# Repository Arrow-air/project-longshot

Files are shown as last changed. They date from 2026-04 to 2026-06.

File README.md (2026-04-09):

# Project Longshot

Custom 21700 Li-ion battery pack for the [Quiver](https://github.com/Arrow-air/project-quiver) drone platform.

## Overview

Longshot replaces the commercial Tattu battery with a custom-built 21700 cell pack, delivering significantly more energy in the same form factor. The pack is designed for open-source tooling and compatibility with the existing Quiver power system.

## Specifications

| Parameter | Value |
|---|---|
| Configuration | 14S 9P (126 cells) |
| Cell format | 21700 Li-ion |
| Energy | ~2,200–2,300 Wh |
| Voltage | 14S (~58.8V charged, ~51.8V nominal) |
| Communication | CAN H/L on main connector |
| Environmental | IP54, 4× temperature sensors |
| Structure | Printed cell holders + casing, aluminum reinforcement |
| Bus bars | Laser-cut 0.2mm copper foil |

## BMS

- **v0 (prototype):** PCB dummy — exposes cell connections, main PCB handles power path
- **v1+:** STM32-based smart BMS (VESC BMS reference design)

## Status

Project approved via [Snapshot vote](https://snapshot.box/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) (April 2026, amends AIP-007).

## Links

- [Proposal discussion](https://dao.arrowair.com/t/project-longshot-proposal-discussion/154)
- [Arrow DAO](https://arrowair.com)
- [Project Quiver](https://github.com/Arrow-air/project-quiver)

## License

See [CONTRIBUTING.md](CONTRIBUTING.md) for contribution guidelines.

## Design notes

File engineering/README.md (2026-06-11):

# Engineering

This folder contains the active design work for Project Longshot.

- `cad/` — mechanical CAD, generated exports, and reference geometry.
- `electronics/` — PCB projects and electronics design files.
- `builds/` — build-specific locked artifacts, order packages, and design records.

Keep durable decisions and explanatory documents in `docs/`. Use GitHub issues and discussions for live work-in-progress updates, then summarize settled outcomes back into the relevant README or ADR.

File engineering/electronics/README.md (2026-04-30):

# Electronics

Longshot electronics design files live here.

## PCB projects

Each PCB should have its own self-contained folder under `pcbs/`. KiCad projects should keep project files under `kicad/` and local libraries under `kicad/libs/` so a contributor can clone/download the PCB folder and open it without missing project-specific components.

Current PCB folders:

- `pcbs/BMSJ/` — Longshot BMSJ battery management system board.
- `pcbs/BMSZ/` — Longshot BMSZ battery management system board.

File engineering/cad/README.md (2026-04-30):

# CAD

Longshot CAD work lives here.

## Folders

- `build123d/` — Python/build123d parametric CAD source.
- `reference/` — imported vendor, measurement, or reference geometry.
- `build123d/exports/` — generated STEP/STL outputs for review, manufacturing, or downstream CAD use.

Generated exports should be reproducible from the source where practical. If an export is hand-edited or comes from another CAD package, document that in the nearest README.

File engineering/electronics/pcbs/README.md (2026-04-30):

# PCB Projects

Each folder in this directory is one self-contained PCB project.

## Required PCB folder contents

```text
PCBNAME/
├── README.md
├── docs/
├── firmware/
├── images/
├── kicad/
│   └── libs/
│       ├── 3dmodels/
│       ├── PCBNAME.pretty/
│       └── PCBNAME.kicad_sym
└── manufacturing/
```

## KiCad conventions

- Put KiCad project files directly under `kicad/`.
- Put project-local symbols, footprints, and 3D models under `kicad/libs/`.
- Use `kicad/libs/PCBNAME.pretty/` for the board's local footprint library.
- Use `kicad/libs/PCBNAME.kicad_sym` for the board's local symbol library.
- Avoid relying on contributor-specific global KiCad libraries for project components. If a component is not from KiCad's standard libraries, include it locally in the PCB folder.

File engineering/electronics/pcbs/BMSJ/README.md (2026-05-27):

# BMSJ

Open-source Battery Management System designed for high-voltage lithium battery packs with VESC integration.

## Longshot Repository Layout

This project was imported from `Julius-eng/Vector-BMS` and adapted into the Project Longshot engineering tree.

- `kicad/` — KiCad project, schematic sheets, PCB, and project-local library tables.
- `kicad/libs/BMSJ.pretty/` — project-local footprints imported from the source repository.
- `firmware/vesc_bms_hw/` — VESC BMS hardware configuration renamed to `hw_bmsj`.
- `docs/`, `images/`, and `manufacturing/` — placeholders for supporting design notes, renders, and fab outputs.

## Overview

BMSJ is a modular BMS supporting up to **24 series cells** (24S) with:
- Active cell monitoring and balancing
- High-current sensing (up to 120A)
- CAN bus communication (VESC-compatible)
- USB interface for configuration
- Isolated design for safety

**Firmware:** This project uses [VESC BMS firmware](https://github.com/vedderb/vesc_bms_fw) for full VESC Tool integration.

## Hardware Architecture

### Schematic Structure

```
BMSJ.kicad_sch (Main)
├── Power management
├── Cell monitoring (LTC6811 × 2)
├── Current sensing (INA226)
├── High-side switching
└── Connectors

MCU.kicad_sch
├── STM32L476 microcontroller
├── CAN interface (isolated via ISO1050)
├── isoSPI interface (LTC6820)
└── USB interface (CP2104)

cell.kicad_sch / cell2.kicad_sch
└── Per-cell balancing circuits (×12 each)
```

### Key Components

| Component | Part Number | Function |
|---|---|---|
| MCU | STM32L476RGT6 | ARM Cortex-M4, 80MHz, low power |
| Cell Monitor | LTC6811-1 (×2) | 12-cell stack monitor, ±1.2mV accuracy |
| isoSPI | LTC6820 | Isolated SPI for LTC6811 daisy chain |
| Current Sensor | INA226 | 16-bit I2C power monitor |
| Shunt Resistor | WSLP5931L1000FEA | 0.1mΩ, 15W, ±1% |
| CAN Transceiver | ISO1050DUBR | Isolated CAN 2.0B |
| USB-UART | CP2104 | USB to UART bridge |
| DC-DC | LM5165 | Wide-input buck converter |
| Balance FET | DMG2305UX-7 | P-ch MOSFET, SOT-23 |
| Balance Resistor | CRCW25123R90JNEA | 3.9Ω, 1W, 2512 |
| High-side Switch | IRFL4105PBF | N-ch logic-level MOSFET |

### Cell Configuration

- **Maximum cells:** 24S (two LTC6811 in daisy chain)
- **Cell voltage range:** 0V to 5V per cell (compatible with most Li-ion/LiFePO4)
- **Balance current:** ~1A per cell @ 4.2V (passive balancing via 3.9Ω resistor)
- **Temperature monitoring:** 3× NTC thermistors

### Current Sensing

- **Shunt:** 0.1mΩ (WSLP5931, 15×7.6mm)
- **Max continuous:** 120A
- **Sensor:** INA226 (16-bit I2C power monitor)
- **Resolution:** ~1mA per LSB
- **Power dissipation:** 1.44W at 120A

## VESC BMS Firmware

BMSJ uses the [VESC BMS firmware](https://github.com/vedderb/vesc_bms_fw) which provides:

- ✅ Cell monitoring and balancing
- ✅ Charge control with CC/CV support
- ✅ Low-power sleep mode
- ✅ CAN-bus integration with VESC motor controllers
- ✅ USB configuration via VESC Tool
- ✅ Ah and Wh counting
- ✅ Distributed balancing across multiple BMSes
- ✅ Bootloader and firmware update support

### Building Firmware

#### Prerequisites

1. **ARM GCC Toolchain**
   ```bash
   # Ubuntu/Debian
   sudo apt install gcc-arm-none-eabi

   # macOS
   brew install arm-none-eabi-gcc

   # Windows: Download from ARM website
   ```

2. **ChibiOS** (included as submodule in VESC BMS)

3. **Make**

#### Clone and Build

```bash
# Clone VESC BMS firmware
git clone --recursive https://github.com/vedderb/vesc_bms_fw.git
cd vesc_bms_fw

# Copy BMSJ hardware config
cp /path/to/project-longshot/engineering/electronics/pcbs/BMSJ/firmware/vesc_bms_hw/hw_bmsj.h hwconf/
cp /path/to/project-longshot/engineering/electronics/pcbs/BMSJ/firmware/vesc_bms_hw/hw_bmsj.c hwconf/

# Build for BMSJ
make HWCONF=hw_bmsj

# Output: build/vesc_bms_fw.bin
```

#### Flashing

Using ST-Link:
```bash
# Flash via OpenOCD
openocd -f interface/stlink.cfg -f target/stm32l4x.cfg \
    -c "program build/vesc_bms_fw.bin 0x08000000 verify reset exit"

# Or via st-flash
st-flash write build/vesc_bms_fw.bin 0x08000000
```

Using VESC Tool (for updates):
1. Connect BMSJ via USB
2. Open VESC Tool
3. Go to **Firmware** → **Bootloader**
4. Select `vesc_bms_fw.bin` and upload

### Hardware Configuration

The BMSJ hardware config is in `firmware/vesc_bms_hw/`:

```
firmware/vesc_bms_hw/
├── hw_bmsj.h     # Pin definitions, parameters
└── hw_bmsj.c     # Initialization, INA226 driver
```

Key parameters in `hw_bmsj.h`:

```c
#define HW_CELLS_SERIES         24          // Cell count
#define HW_SHUNT_RES            (0.1e-3)    // Shunt resistance
#define HW_INA226_I2C_ADDR      0x40        // INA226 address
```

### VESC Tool Configuration

1. Connect BMSJ via USB
2. Open VESC Tool and connect
3. Go to **VESC BMS** tab
4. Configure:
   - Cell count: 24
   - Balance start voltage
   - Balance delta voltage
   - Current limits
   - Temperature limits
5. **Write Configuration**

## MCU Pin Mapping

| Function | STM32 Pin | Notes |
|---|---|---|
| SPI1_NSS (LTC6820) | PA4 | Directly driven CS |
| SPI1_SCK | PA5 | isoSPI clock |
| SPI1_MISO | PA6 | isoSPI data in |
| SPI1_MOSI | PA7 | isoSPI data out |
| I2C1_SDA (INA226) | PB7 | Current sensor |
| I2C1_SCL | PB6 | Current sensor |
| CAN1_RX | PB8 | Via ISO1050 |
| CAN1_TX | PB9 | Via ISO1050 |
| USART1_TX | PA9 | Via CP2104 to USB |
| USART1_RX | PA10 | Via CP2104 to USB |
| CHG_EN | PC6 | Charge enable |
| DSG_EN | PC7 | Discharge enable |
| PCHG_EN | PC8 | Precharge enable |
| LED_RED | PA0 | Status LED |
| LED_GREEN | PA1 | Power LED |
| BUZZER | PA8 | Audible alarm |

## Connectors

| Connector | Function |
|---|---|
| J1 | Main battery input |
| J2 | Charger input |
| J3 | OLED display (I2C) |
| J12 | CAN bus |
| J14 | Serial/debug |
| J17 | Power button |
| J24 | USB (CP2104) |

## Hardware Design

### Prerequisites

- KiCad 9.0+ for schematic/PCB editing

### Opening the Project

1. Clone the repository
2. Open `kicad/BMSJ.kicad_pro` in KiCad
3. Review schematic and PCB layout
4. Generate BOM and fabrication files

## License

Hardware: Open Source (license TBD)
Firmware: GNU GPL v3 (VESC BMS)

## Contributing

Contributions welcome! Please open an issue or pull request.

## Acknowledgments

- [Benjamin Vedder](https://github.com/vedderb) for VESC BMS firmware
- VESC Project for the open-source motor controller ecosystem
- Analog Devices for LTC6811 reference designs
- Arrow DAO community

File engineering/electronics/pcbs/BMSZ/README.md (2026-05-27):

# BMSZ

Open-source Battery Management System designed for high-voltage lithium battery packs with VESC integration.

## Longshot Repository Layout

This project was imported from `Julius-eng/Vector-BMS` and adapted into the Project Longshot engineering tree.

- `kicad/` — KiCad project, single-sheet schematic, PCB, and project-local library tables.
- `kicad/libs/BMSZ.pretty/` — project-local footprints imported from the source repository.
- `firmware/vesc_bms_hw/` — VESC BMS hardware configuration renamed to `hw_bmsz`.
- `docs/`, `images/`, and `manufacturing/` — placeholders for supporting design notes, renders, and fab outputs.

## Overview

BMSZ is a modular BMS supporting up to **24 series cells** (24S) with:
- Active cell monitoring and balancing
- High-current sensing (up to 120A)
- CAN bus communication (VESC-compatible)
- USB interface for configuration
- Isolated design for safety

**Firmware:** This project uses [VESC BMS firmware](https://github.com/vedderb/vesc_bms_fw) for full VESC Tool integration.

## Hardware Architecture

### Schematic Structure

`BMSZ.kicad_sch` is currently reduced to a single basic-layout schematic. The previous copied hierarchy (`MCU.kicad_sch`, `cell.kicad_sch`, and `cell2.kicad_sch`) has been removed from this simplified layout.

### Key Components

| Component | Part Number | Function |
|---|---|---|
| MCU | STM32L476RGT6 | ARM Cortex-M4, 80MHz, low power |
| Cell Monitor | LTC6811-1 (×2) | 12-cell stack monitor, ±1.2mV accuracy |
| isoSPI | LTC6820 | Isolated SPI for LTC6811 daisy chain |
| Current Sensor | INA226 | 16-bit I2C power monitor |
| Shunt Resistor | WSLP5931L1000FEA | 0.1mΩ, 15W, ±1% |
| CAN Transceiver | ISO1050DUBR | Isolated CAN 2.0B |
| USB-UART | CP2104 | USB to UART bridge |
| DC-DC | LM5165 | Wide-input buck converter |
| Balance FET | DMG2305UX-7 | P-ch MOSFET, SOT-23 |
| Balance Resistor | CRCW25123R90JNEA | 3.9Ω, 1W, 2512 |
| High-side Switch | IRFL4105PBF | N-ch logic-level MOSFET |

### Cell Configuration

- **Maximum cells:** 24S (two LTC6811 in daisy chain)
- **Cell voltage range:** 0V to 5V per cell (compatible with most Li-ion/LiFePO4)
- **Balance current:** ~1A per cell @ 4.2V (passive balancing via 3.9Ω resistor)
- **Temperature monitoring:** 3× NTC thermistors

### Current Sensing

- **Shunt:** 0.1mΩ (WSLP5931, 15×7.6mm)
- **Max continuous:** 120A
- **Sensor:** INA226 (16-bit I2C power monitor)
- **Resolution:** ~1mA per LSB
- **Power dissipation:** 1.44W at 120A

## VESC BMS Firmware

BMSZ uses the [VESC BMS firmware](https://github.com/vedderb/vesc_bms_fw) which provides:

- ✅ Cell monitoring and balancing
- ✅ Charge control with CC/CV support
- ✅ Low-power sleep mode
- ✅ CAN-bus integration with VESC motor controllers
- ✅ USB configuration via VESC Tool
- ✅ Ah and Wh counting
- ✅ Distributed balancing across multiple BMSes
- ✅ Bootloader and firmware update support

### Building Firmware

#### Prerequisites

1. **ARM GCC Toolchain**
   ```bash
   # Ubuntu/Debian
   sudo apt install gcc-arm-none-eabi

   # macOS
   brew install arm-none-eabi-gcc

   # Windows: Download from ARM website
   ```

2. **ChibiOS** (included as submodule in VESC BMS)

3. **Make**

#### Clone and Build

```bash
# Clone VESC BMS firmware
git clone --recursive https://github.com/vedderb/vesc_bms_fw.git
cd vesc_bms_fw

# Copy BMSZ hardware config
cp /path/to/project-longshot/engineering/electronics/pcbs/BMSZ/firmware/vesc_bms_hw/hw_bmsz.h hwconf/
cp /path/to/project-longshot/engineering/electronics/pcbs/BMSZ/firmware/vesc_bms_hw/hw_bmsz.c hwconf/

# Build for BMSZ
make HWCONF=hw_bmsz

# Output: build/vesc_bms_fw.bin
```

#### Flashing

Using ST-Link:
```bash
# Flash via OpenOCD
openocd -f interface/stlink.cfg -f target/stm32l4x.cfg \
    -c "program build/vesc_bms_fw.bin 0x08000000 verify reset exit"

# Or via st-flash
st-flash write build/vesc_bms_fw.bin 0x08000000
```

Using VESC Tool (for updates):
1. Connect BMSZ via USB
2. Open VESC Tool
3. Go to **Firmware** → **Bootloader**
4. Select `vesc_bms_fw.bin` and upload

### Hardware Configuration

The BMSZ hardware config is in `firmware/vesc_bms_hw/`:

```
firmware/vesc_bms_hw/
├── hw_bmsz.h     # Pin definitions, parameters
└── hw_bmsz.c     # Initialization, INA226 driver
```

Key parameters in `hw_bmsz.h`:

```c
#define HW_CELLS_SERIES         24          // Cell count
#define HW_SHUNT_RES            (0.1e-3)    // Shunt resistance
#define HW_INA226_I2C_ADDR      0x40        // INA226 address
```

### VESC Tool Configuration

1. Connect BMSZ via USB
2. Open VESC Tool and connect
3. Go to **VESC BMS** tab
4. Configure:
   - Cell count: 24
   - Balance start voltage
   - Balance delta voltage
   - Current limits
   - Temperature limits
5. **Write Configuration**

## MCU Pin Mapping

| Function | STM32 Pin | Notes |
|---|---|---|
| SPI1_NSS (LTC6820) | PA4 | Directly driven CS |
| SPI1_SCK | PA5 | isoSPI clock |
| SPI1_MISO | PA6 | isoSPI data in |
| SPI1_MOSI | PA7 | isoSPI data out |
| I2C1_SDA (INA226) | PB7 | Current sensor |
| I2C1_SCL | PB6 | Current sensor |
| CAN1_RX | PB8 | Via ISO1050 |
| CAN1_TX | PB9 | Via ISO1050 |
| USART1_TX | PA9 | Via CP2104 to USB |
| USART1_RX | PA10 | Via CP2104 to USB |
| CHG_EN | PC6 | Charge enable |
| DSG_EN | PC7 | Discharge enable |
| PCHG_EN | PC8 | Precharge enable |
| LED_RED | PA0 | Status LED |
| LED_GREEN | PA1 | Power LED |
| BUZZER | PA8 | Audible alarm |

## Connectors

| Connector | Function |
|---|---|
| J1 | Main battery input |
| J2 | Charger input |
| J3 | OLED display (I2C) |
| J12 | CAN bus |
| J14 | Serial/debug |
| J17 | Power button |
| J24 | USB (CP2104) |

## Hardware Design

### Prerequisites

- KiCad 9.0+ for schematic/PCB editing

### Opening the Project

1. Clone the repository
2. Open `kicad/BMSZ.kicad_pro` in KiCad
3. Review schematic and PCB layout
4. Generate BOM and fabrication files

## License

Hardware: Open Source (license TBD)
Firmware: GNU GPL v3 (VESC BMS)

## Contributing

Contributions welcome! Please open an issue or pull request.

## Acknowledgments

- [Benjamin Vedder](https://github.com/vedderb) for VESC BMS firmware
- VESC Project for the open-source motor controller ecosystem
- Analog Devices for LTC6811 reference designs
- Arrow DAO community

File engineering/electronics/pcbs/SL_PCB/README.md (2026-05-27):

# SL_PCB — Simple Layout Battery Connector PCB

`SL_PCB` is the **dummy/simple-layout PCB** for the Longshot battery. It is not a full BMS board.

The purpose of this board is to:

1. Route high-current power from the battery to the battery connector.
2. Place an **AMX-150 fuse** in the high-current path.
3. Provide a normal exposed charging connector that can be connected to the **Tattu TA3200 charger** with a dedicated charge cable.
4. Collect cell-voltage sense lines from the four voltage sensing PCBs.
5. Expose those cell-voltage sense lines through a connector compatible with the balancing cable of a **Tattu TA3200 charger**.

This board intentionally does **not** include MOSFET switching, active balancing, MCU control, or BMS firmware functionality.

## Current role in Longshot

The SL_PCB is a low-complexity bridge board for early Longshot battery testing and packaging work. It should keep the electrical path understandable and easy to inspect while the full BMS architecture is still being developed separately.

## High-current path

The high-current path should route battery power directly to the battery connector, with one fuse in series. The board should also expose a normal charging connector that can be connected to the TA3200 charger using a dedicated charge cable.

```text
Battery high-current terminal → AMX-150 fuse → Battery connector
                                      └→ Exposed charging connector for TA3200 charge cable
```

Design notes:

- Use copper geometry appropriate for the expected current path.
- Keep the fuse accessible and easy to inspect where practical.
- Do not add MOSFETs, precharge circuitry, current sensing, or BMS switching logic to this PCB unless the project scope changes.
- Include a normal exposed charging connector for the TA3200 charge cable connection.
- Maintain clear creepage/clearance and mechanical separation between the high-current/charging path and low-voltage sense routing.

## Cell-voltage sensing interface

Cell voltages are collected by the voltage sensing PCBs from issue #14:

- `VS_PCB_TR`
- `VS_PCB_TL`
- `VS_PCB_BR`
- `VS_PCB_BL`

Each voltage sensing PCB connects to SL_PCB through a **6-pin JST connector**:

- 3–4 cell voltage sense lines, depending on the board
- `GND`
- `T_SENSE` for the temperature sensor connection

Related issue: [#14 — Design battery voltage sensing boards](https://github.com/Arrow-air/project-longshot/issues/14)

## Charger connectors

SL_PCB should expose both charger-facing connections needed by the **Tattu TA3200 charger**:

1. A main charging connector for the dedicated TA3200 charge cable.
2. A balancing connector that mates with the TA3200 balancing cable and carries the collected cell-voltage sense lines.

Reference images:

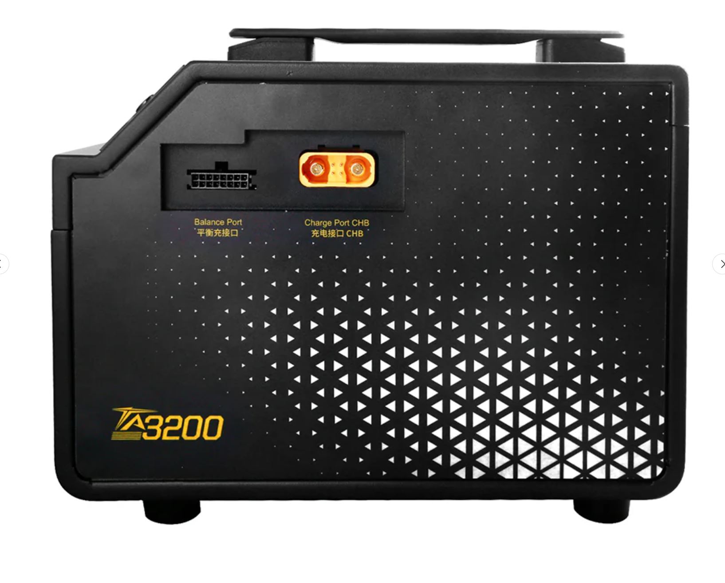
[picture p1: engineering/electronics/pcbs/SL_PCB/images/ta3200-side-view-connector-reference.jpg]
Tattu TA3200 charger side connector reference


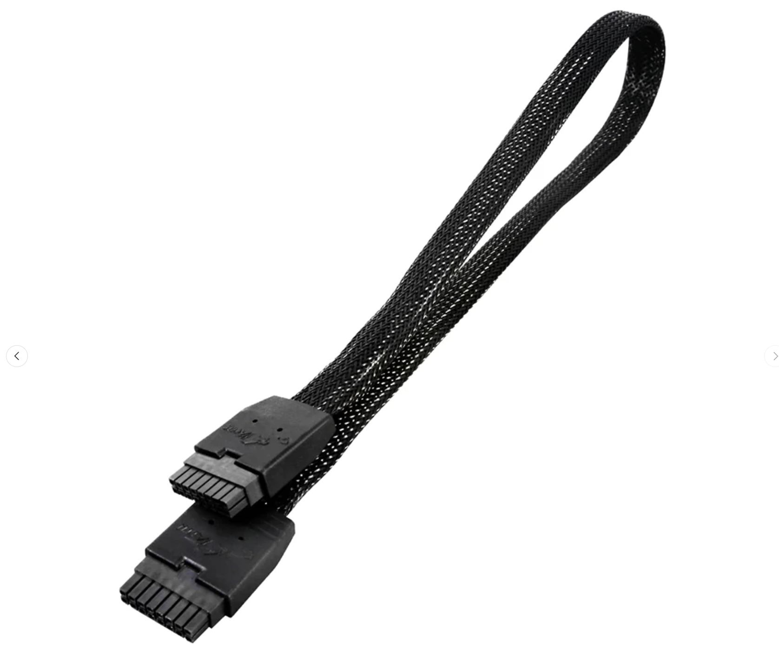
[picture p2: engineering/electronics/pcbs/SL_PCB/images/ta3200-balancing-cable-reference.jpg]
Tattu TA3200 balancing cable reference


Connector notes from the reference images:

- The charger side view shows a recessed connector area with a balance port and a separate orange main charge port.
- The balance cable uses black, flat, shrouded connector housings.
- The connectors appear keyed/polarized with molded side features.
- The exact connector series, pin pitch, pin numbers, and polarity must be verified from the actual charger/cable, charger documentation, or connector datasheet before fabrication.
- Do not rely on the images alone for pin mapping or mechanical footprint selection.

## Critical requirements

- The voltage sense pin mapping must be correct before the board is connected to a charger.
- The four 6-pin JST inputs from the voltage sensing boards must map cleanly to the charger balancing connector.
- Connector orientation and pin numbers must be documented in the schematic and README once finalized.
- The AMX-150 fuse must be in the high-current path.
- The board must include a normal exposed charging connector for a dedicated cable to the TA3200 charger.
- No MOSFET or BMS functionality should be added to this simple-layout board.

## KiCad project

Open the project with KiCad 9.0+:

```text
engineering/electronics/pcbs/SL_PCB/kicad/SL_PCB.kicad_pro
```

Expected project outputs:

- Updated schematic showing:
  - Battery high-current input/output path
  - AMX-150 fuse
  - Exposed TA3200 charge-cable connector
  - 4× 6-pin JST voltage-sense inputs
  - TA3200-compatible balancing connector output
- Updated PCB layout with the corresponding connector placement and high-current routing
- Fabrication outputs when the layout is ready for review/manufacture

## Open items

- Confirm exact TA3200 balancing connector part number and footprint.
- Confirm exact TA3200 charge connector/cable interface and footprint.
- Confirm the final sense-line ordering from each `VS_PCB_*` board.
- Confirm the complete mapping from the four 6-pin JST inputs to the TA3200 balancing connector.
- Confirm mechanical placement of connectors relative to the Longshot battery assembly.

## License

Hardware: Open Source (license TBD)

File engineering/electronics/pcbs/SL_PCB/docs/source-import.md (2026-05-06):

# Source Import

SL_PCB was imported from [`Julius-eng/Vector-BMS`](https://github.com/Julius-eng/Vector-BMS) and adapted into the Project Longshot engineering layout.

Imported:

- KiCad project, schematic sheets, and PCB as `kicad/SL_PCB.*`
- VESC BMS hardware configuration under `firmware/vesc_bms_hw/`, renamed to `hw_sl_pcb.*`
- Project footprint(s) under `kicad/libs/SL_PCB.pretty/`
- Source README content, adapted for the Longshot folder structure

Not imported:

- KiCad lock/cache files
- KiCad auto-backup zip files

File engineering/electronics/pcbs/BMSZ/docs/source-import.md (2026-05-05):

# Source Import

BMSZ was imported from [`Julius-eng/Vector-BMS`](https://github.com/Julius-eng/Vector-BMS) and adapted into the Project Longshot engineering layout.

Imported:

- KiCad project, schematic sheets, and PCB as `kicad/BMSZ.*`
- VESC BMS hardware configuration under `firmware/vesc_bms_hw/`, renamed to `hw_bmsz.*`
- Project footprint(s) under `kicad/libs/BMSZ.pretty/`
- Source README content, adapted for the Longshot folder structure

Not imported:

- KiCad lock/cache files
- KiCad auto-backup zip files

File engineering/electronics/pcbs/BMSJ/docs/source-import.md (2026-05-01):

# Source Import

BMSJ was imported from [`Julius-eng/Vector-BMS`](https://github.com/Julius-eng/Vector-BMS) and adapted into the Project Longshot engineering layout.

Imported:

- KiCad project, schematic sheets, and PCB as `kicad/BMSJ.*`
- VESC BMS hardware configuration under `firmware/vesc_bms_hw/`, renamed to `hw_bmsj.*`
- Project footprint(s) under `kicad/libs/BMSJ.pretty/`
- Source README content, adapted for the Longshot folder structure

Not imported:

- KiCad lock/cache files
- KiCad auto-backup zip files

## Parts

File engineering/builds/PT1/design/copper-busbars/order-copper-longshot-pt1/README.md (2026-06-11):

# Longshot PT1 Copper Busbar Order

These DXF files are the locked copper busbar designs for the Longshot PT1 build. Julius marked these parts as ordered on 2026-06-11, so this directory is intended to preserve the exact manufacturing/order geometry used for PT1.

## Contents

| File | Qty | Copper thickness | SHA-256 |
| --- | ---: | --- | --- |
| `10X_0.2mm_copper_PW-BUS-001-N_Terminal.dxf` | 10 | 0.2mm | `970ad2e5a983f069d3ff543b70fd3756b3dd4cc0a46865a815befa38f23c7237` |
| `10X_0.2mm_copper_PW-BUS-002-P_Terminal.dxf` | 10 | 0.2mm | `a7c3b03e964ea35fc89ada2bd65f9c2f5140897dc5ea4c5303841f19a1deef13` |
| `40X_0.2mm_copper_PW-BUS-003-Bridge_1.dxf` | 40 | 0.2mm | `f8d6f4bbec5d25a08af1b8afe2b8f208ac60896fad28136cf3f5e82c3edbb539` |
| `5X_0.2mm_copper_PW-BUS-004-Bridge_2.dxf` | 5 | 0.2mm | `4fa45a2d4734e6f5ba65785158b096da8a2e360971641d4d2286237f4f1c7a4f` |
| `5X_6mm_copper_PW-BUS-005-Screw_Terminal_Negative.dxf` | 5 | 6mm | `cd6a26158be28e358cc48663c9117fa22360210fa504df3a6daa502f0b72ee06` |
| `5X_6mm_copper_PW-BUS-006-Screw_Terminal_Positive.dxf` | 5 | 6mm | `47d5d5a4e84d7aa15a8e09ab287292bbfa5e6b20095b28e57c7b768a735ce261` |

## Supplier quotation

Source: redacted Supro Manufacturing quotation shared by Julius in `#project-longshot-general` on 2026-06-11.

Price term: DDU by air. Currency: USD. Validity: 15 days from quotation date.

| Quoted file / service | Quoted material | Quoted qty | Unit price | Line total |
| --- | --- | ---: | ---: | ---: |
| `5X_0.2mm_copper_PW-BUS-004-Bridge_2.dxf` | Brass H62 | 5 | $6.80 | $34.00 |
| `5X_6mm_copper_PW-BUS-005-Screw_Terminal_Negative.dxf` | Copper C101 | 5 | $11.30 | $56.50 |
| `5X_6mm_copper_PW-BUS-006-Screw_Terminal_Positive.dxf` | Copper C101 | 5 | $10.20 | $51.00 |
| `10X_0.2mm_copper_PW-BUS-001-N_Terminal.dxf` | Brass H62 | 10 | $3.40 | $34.00 |
| `10X_0.2mm_copper_PW-BUS-002-P_Terminal.dxf` | Brass H62 | 10 | $3.40 | $34.00 |
| `40X_0.2mm_copper_PW-BUS-003-Bridge_1.dxf` | Brass H62 | 40 | $3.40 | $136.00 |
| Shipping | — | — | — | $98.00 |

Quoted parts subtotal: $345.50. Quoted total with shipping: $443.50.

## Per-prototype busbar estimate

Julius noted the quoted order is material for approximately three batteries. One prototype battery needs:

| Part | Prototype qty | Quoted unit price | Prototype line cost |
| --- | ---: | ---: | ---: |
| `PW-BUS-001-N_Terminal.dxf` | 1 | $3.40 | $3.40 |
| `PW-BUS-002-P_Terminal.dxf` | 1 | $3.40 | $3.40 |
| `PW-BUS-003-Bridge_1.dxf` | 12 | $3.40 | $40.80 |
| `PW-BUS-004-Bridge_2.dxf` | 1 | $6.80 | $6.80 |
| `PW-BUS-005-Screw_Terminal_Negative.dxf` | 1 | $11.30 | $11.30 |
| `PW-BUS-006-Screw_Terminal_Positive.dxf` | 1 | $10.20 | $10.20 |

Estimated per-prototype parts subtotal: $75.90.

With shipping spread over three prototype batteries, estimated per-prototype delivered cost is $108.57.

For a simple order-total allocation, $443.50 divided by three batteries is $147.83 per battery, including the extra quoted spares/overage.

## Notes

- Source files: Discord upload `Order_Copper_Longshot_PT1.7z` from Julius in `#project-longshot-general`.
- Source quotation: Discord upload `Supro_Quotation_geschwarzt.pdf` from Julius in `#project-longshot-general`.
- Files are stored unpacked instead of as a compressed archive so they can be reviewed and versioned directly in GitHub.
- Treat these as PT1 build record artifacts. Future copper revisions should go in a new revision/build directory rather than modifying these files in place.

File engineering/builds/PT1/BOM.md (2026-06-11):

# Longshot PT1 BOM and Cost Notes

This page records the ordered PT1 prototype materials where supplier quote/order data is available.

## Battery cells

Source: redacted Alibaba receipt `L_001.pdf` shared by Julius in `#project-longshot-general` on 2026-06-11.

| Field | Value |
| --- | --- |
| Supplier | Shenzhen Vapcell Technology Co., Ltd. |
| Marketplace | Alibaba.com |
| Ordered cell | BAK 21700 65E cylindrical Li-ion cell |
| Listing description | New Arrivals Battery 2026 Brand BAK 21700 65E 6500mAh Cylindrical Lithium Ion Batteries 25A 3.6V for Ebike Drones |
| Nominal capacity | 6500mAh |
| Nominal voltage | 3.6V |
| Continuous discharge rating | 25A |
| PT1 pack configuration | 14S 9P |
| Cells used in pack | 126 |
| Cells ordered | 140 |
| Spare/overage cells | 14 |

### Cell order cost

Receipt currency: EUR. Contract currency shown on receipt: USD.

| Cost item | EUR | USD |
| --- | ---: | ---: |
| Cell subtotal, 140 pcs | €662.17 | — |
| Shipping | €145.13 | — |
| Logistics insurance | €24.22 | — |
| Order total before payment fee | €831.51 | $951.10 |
| Payment processing fee | €24.88 | — |
| Amount paid / landed order total | €856.39 | $979.55 |

Per ordered cell landed cost: **€6.12/cell** (about **$7.00/cell**, using the receipt totals).

Allocated to the 126 cells installed in the 14S 9P PT1 pack: **€770.75** (about **$881.60**).

The remaining 14 cells represent **€85.64** (about **$97.96**) of spares/overage from the order.

### Cell selection rationale

The BAK 65E cells were relatively expensive for this PT1 order, but Julius selected them because they were in stock and close to the best-performing 21700 cells available at order time. Julius initially tried to source Reliance RH60 cells, which were around $3/cell, but those were only available at the end of June.

Julius shared the following 10A discharge comparison, measured as energy delivered to 2.8V:

| Cell | Energy to 2.8V at 10A |
| --- | ---: |
| BAK 65E | 20.18Wh |
| Reliance RS60 | 19.25Wh |
| Linkdata 60P | 18.69Wh |
| Reliance RH60 | 18.56Wh |
| FEB 21700G (58E) | 18.53Wh |
| Vapcell F63 | 18.19Wh |
| Amprius INR21700/65 (SA112) | 18.16Wh |
| EVE 58E | 17.88Wh |
| Vapcell F60 | 17.86Wh |
| Samsung 58E | 17.56Wh |
| LG M58T | 17.22Wh |

## Copper busbars

Source: redacted Supro Manufacturing quotation shared by Julius in `#project-longshot-general` on 2026-06-11. Detailed quote and per-part breakdown are in [`design/copper-busbars/order-copper-longshot-pt1/`](design/copper-busbars/order-copper-longshot-pt1/).

| Cost basis | USD |
| --- | ---: |
| One-prototype parts subtotal from required PT1 quantities | $75.90 |
| One-prototype delivered estimate with shipping spread over 3 batteries | $108.57 |
| Simple quoted-order allocation including spares/overage, $443.50 / 3 | $147.83 |

## Current known PT1 material cost

These totals include only the ordered cells and copper busbars documented above. They do not include PCBs, printed/structural parts, enclosure hardware, connectors, labor, or tooling.

| Cost basis | Known PT1 material cost |
| --- | ---: |
| Installed cells + busbar delivered estimate | about $990.17 |
| Full cell order + busbar simple allocation including spares/overage | about $1,127.38 |

Keep currencies explicit when adding new line items; use the supplier receipt currency first and add converted totals only when the source document provides an exchange rate or USD total.

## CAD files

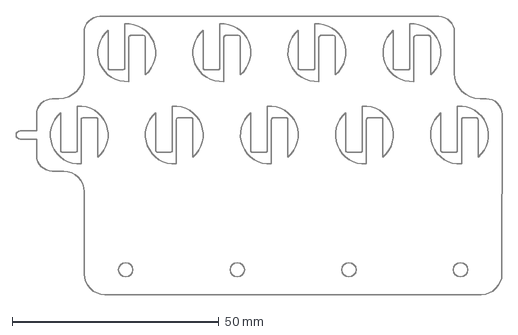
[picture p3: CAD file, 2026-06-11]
engineering/builds/PT1/design/copper-busbars/order-copper-longshot-pt1/10X_0.2mm_copper_PW-BUS-001-N_Terminal.dxf
117.6 x 67.3 mm

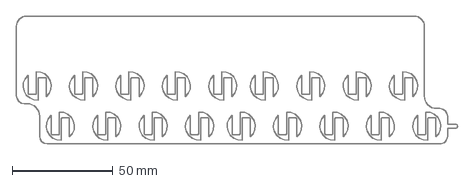
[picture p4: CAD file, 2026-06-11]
engineering/builds/PT1/design/copper-busbars/order-copper-longshot-pt1/5X_0.2mm_copper_PW-BUS-004-Bridge_2.dxf
218.7 x 63.3 mm

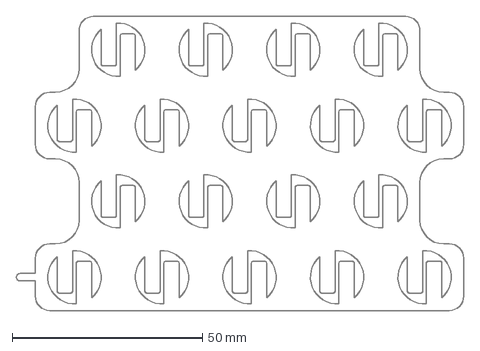
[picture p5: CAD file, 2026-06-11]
engineering/builds/PT1/design/copper-busbars/order-copper-longshot-pt1/40X_0.2mm_copper_PW-BUS-003-Bridge_1.dxf
117.6 x 77.3 mm

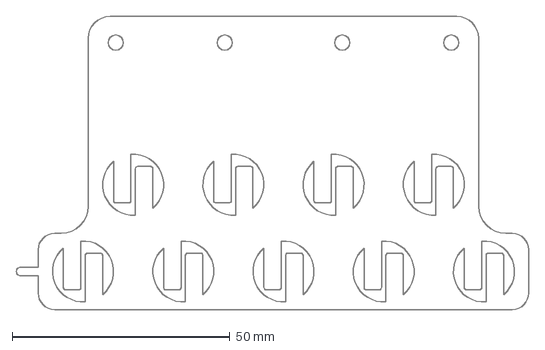
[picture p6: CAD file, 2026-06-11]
engineering/builds/PT1/design/copper-busbars/order-copper-longshot-pt1/10X_0.2mm_copper_PW-BUS-002-P_Terminal.dxf
117.6 x 67.3 mm

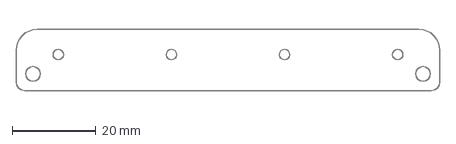
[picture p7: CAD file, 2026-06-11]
engineering/builds/PT1/design/copper-busbars/order-copper-longshot-pt1/5X_6mm_copper_PW-BUS-005-Screw_Terminal_Negative.dxf
101.1 x 14.6 mm

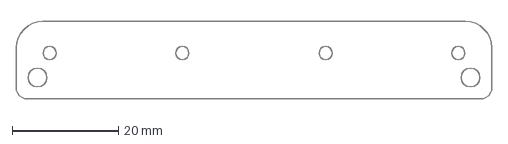
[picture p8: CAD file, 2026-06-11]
engineering/builds/PT1/design/copper-busbars/order-copper-longshot-pt1/5X_6mm_copper_PW-BUS-006-Screw_Terminal_Positive.dxf
89.6 x 14.6 mm

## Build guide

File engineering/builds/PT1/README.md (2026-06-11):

# Longshot PT1 Build

This directory records design and manufacturing artifacts that are locked or used for the Longshot PT1 build.

## Build records

- [`BOM.md`](BOM.md) — PT1 bill-of-materials and cost notes for ordered cells and copper busbars.

## Design artifacts

- [`design/copper-busbars/order-copper-longshot-pt1/`](design/copper-busbars/order-copper-longshot-pt1/) — locked copper busbar DXF order set received from Julius on 2026-06-11.

## Change policy

Files in this build directory are build-record artifacts. If PT1 hardware changes after an order is placed, add a new clearly named revision directory and document the change instead of overwriting the locked order set.

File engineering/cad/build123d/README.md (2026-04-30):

# build123d CAD

Parametric CAD source for Longshot build123d models.

## Suggested layout

- `src/` — Python source for models and assemblies.
- `exports/step/` — generated STEP files.
- `exports/stl/` — generated STL files.
- `reference/` — local reference geometry used by build scripts.

Add setup and export commands here once the first build123d model is committed.

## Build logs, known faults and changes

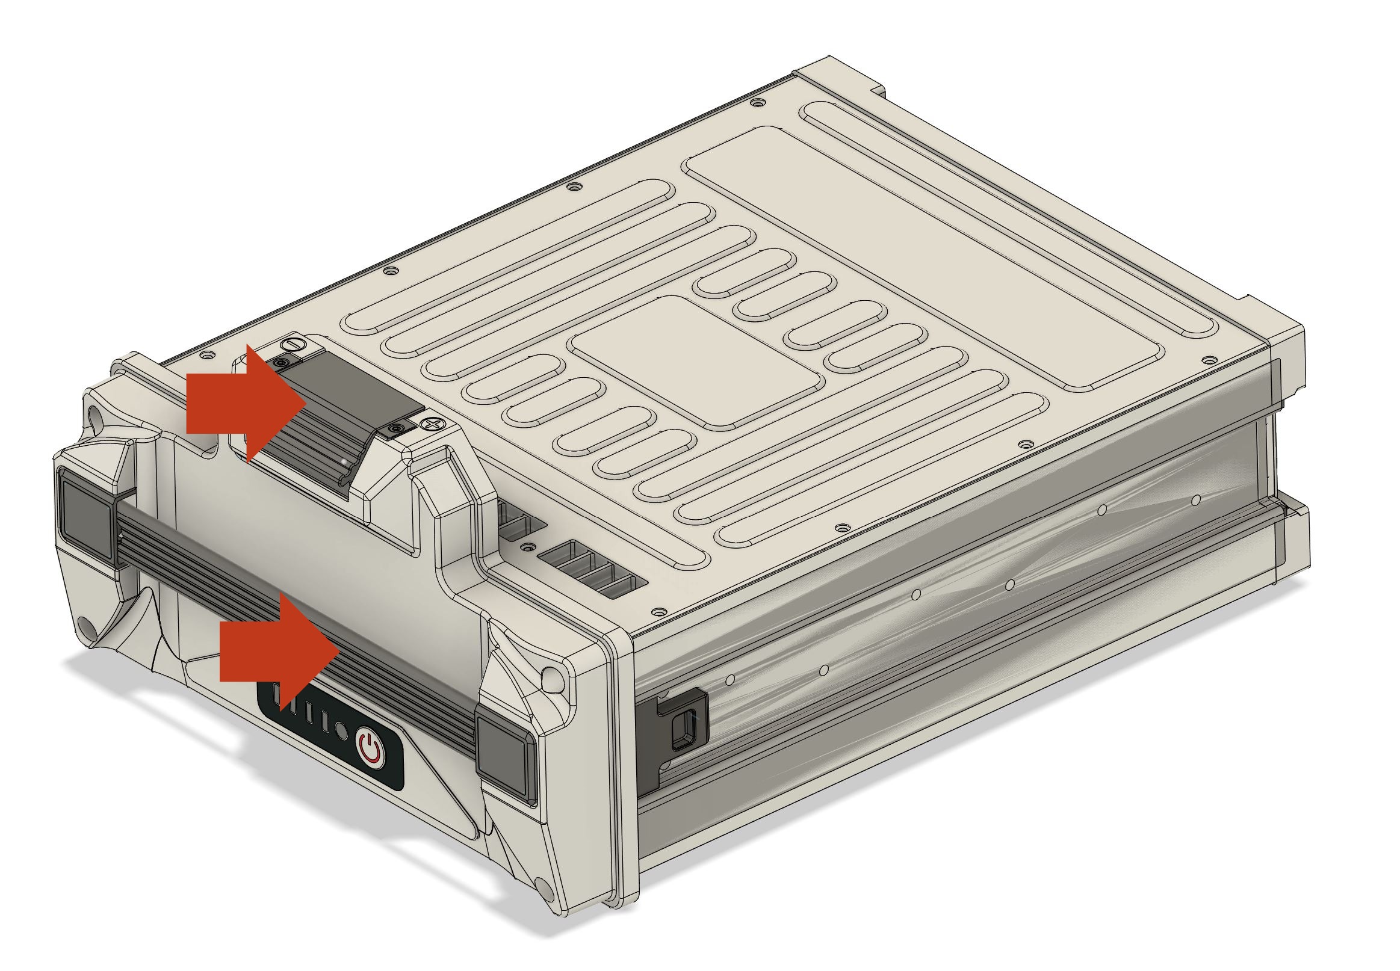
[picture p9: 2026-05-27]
docs/issue-assets/longshot-battery-work-packages/issue-12-tattu-top-reference.jpg

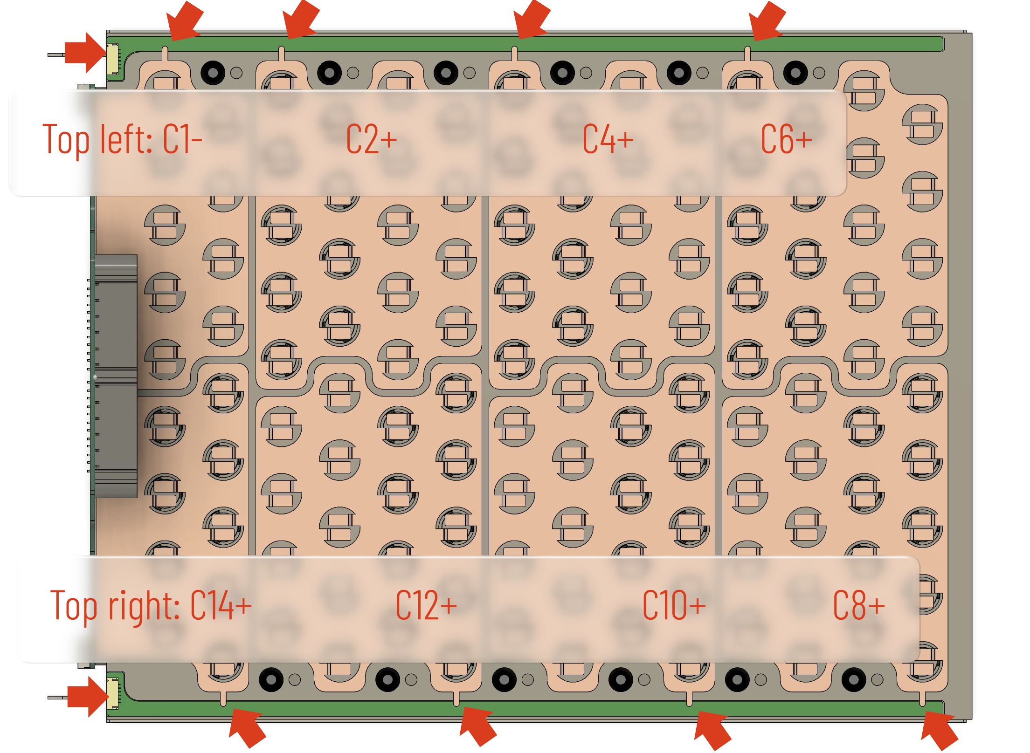
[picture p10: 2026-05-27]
docs/issue-assets/longshot-battery-work-packages/issue-14-voltage-sense-board-reference.jpg

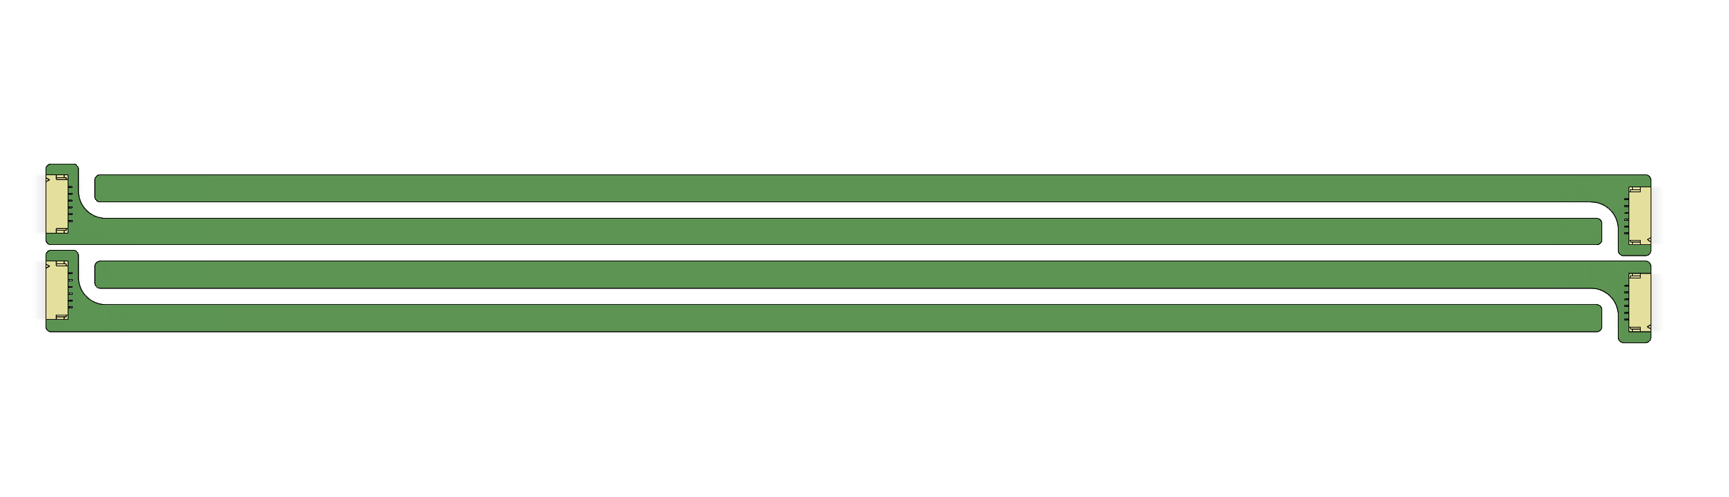
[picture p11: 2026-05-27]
docs/issue-assets/longshot-battery-work-packages/issue-14-voltage-sense-panelization-demo.png

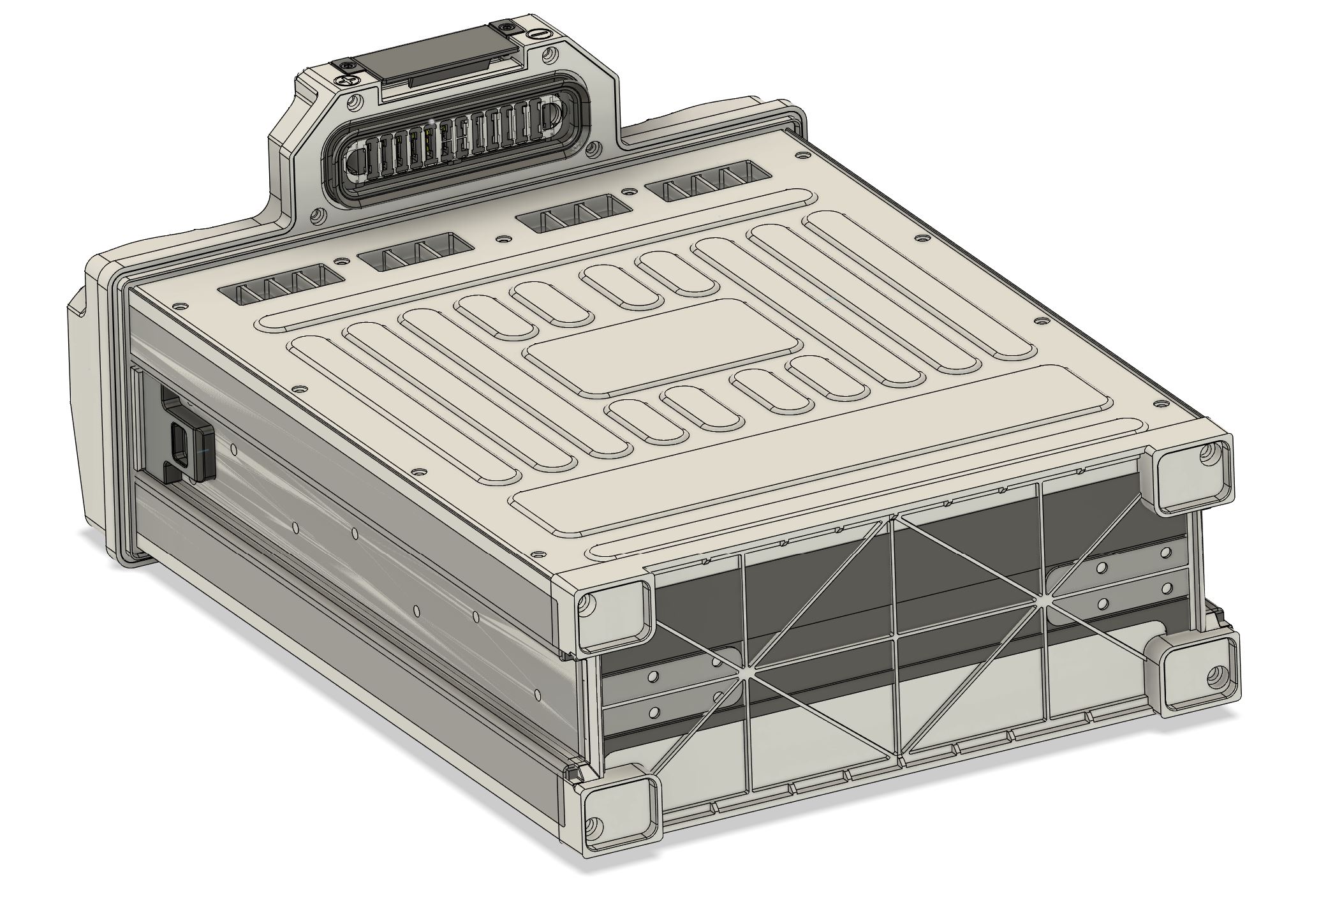
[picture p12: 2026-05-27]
docs/issue-assets/longshot-battery-work-packages/issue-11-tattu-base-reference.jpg

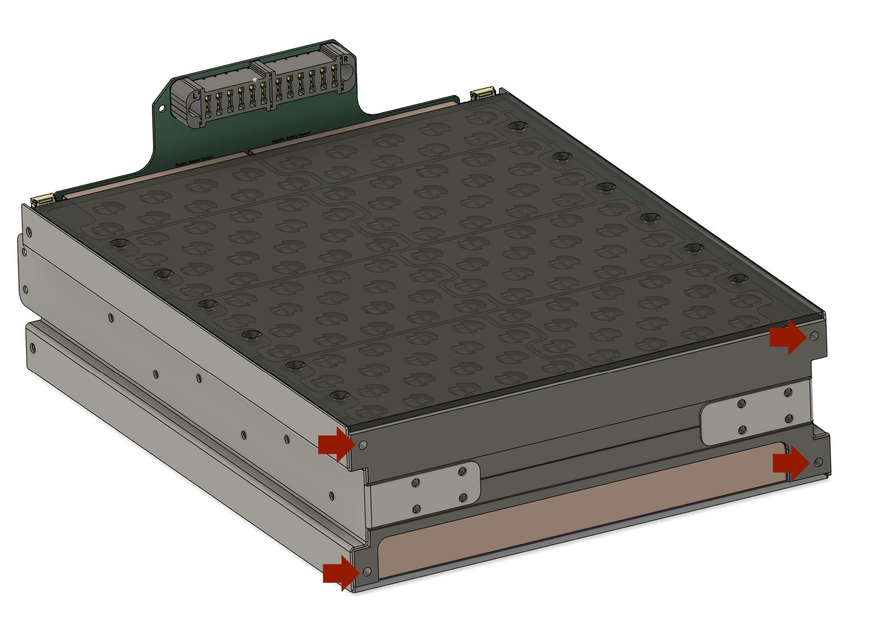
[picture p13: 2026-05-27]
docs/issue-assets/longshot-battery-work-packages/issue-11-current-base-mounting.jpg

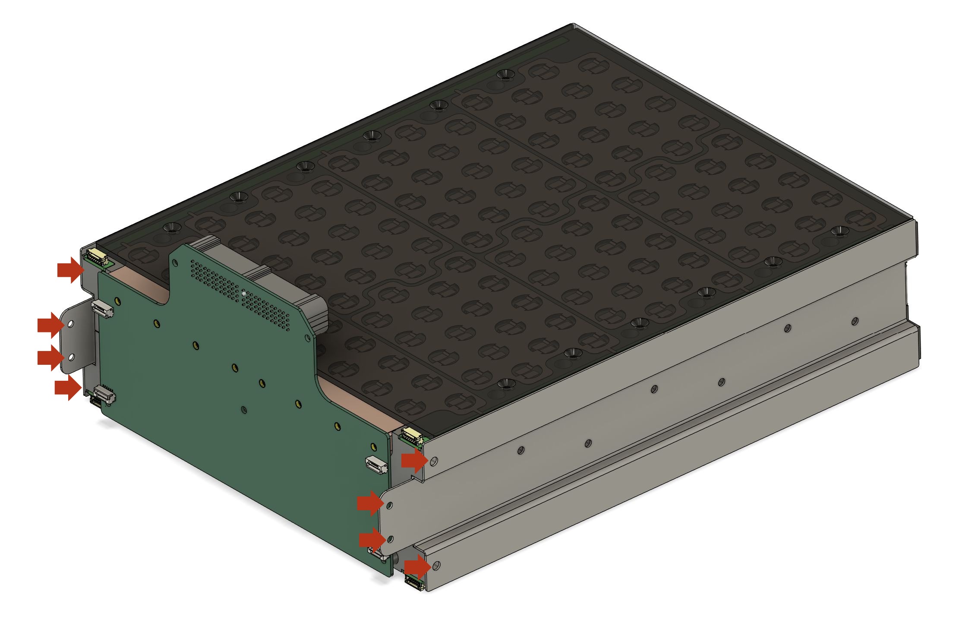
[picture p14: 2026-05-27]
docs/issue-assets/longshot-battery-work-packages/issue-12-current-top-cover-area.jpg

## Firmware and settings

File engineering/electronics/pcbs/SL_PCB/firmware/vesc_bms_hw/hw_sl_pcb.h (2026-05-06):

/*
    Copyright 2024 Benjamin Vedder  benjamin@vedder.se
    Copyright 2024 SL_PCB Contributors

    This file is part of the VESC BMS firmware.

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
    You should have received a copy of the GNU General Public License
    along with this program.  If not, see <http://www.gnu.org/licenses/>.
*/

#ifndef HWCONF_HW_SL_PCB_H_
#define HWCONF_HW_SL_PCB_H_

#define HW_NAME                 "SL_PCB"

/*===========================================================================*/
/* Cell Configuration                                                        */
/*===========================================================================*/

#define HW_CELLS_SERIES         24          // 2x LTC6811 in daisy chain
#define HW_LTC_COUNT            2           // Number of LTC6811 ICs

/*===========================================================================*/
/* Current Sensing - INA226                                                  */
/*===========================================================================*/

// Using INA226 via I2C instead of analog shunt amplifier
#define HW_HAS_INA226
#define HW_INA226_I2C_ADDR      0x40

#define HW_SHUNT_RES            (0.1e-3)    // 0.1 mOhm (WSLP5931L1000FEA)
#define HW_INA226_CAL           51200       // Calibration for 1mA/LSB

// No analog current measurement
#undef HW_HAS_ANALOG_CURRENT

/*===========================================================================*/
/* LTC6811 via LTC6820 isoSPI                                               */
/*===========================================================================*/

// SPI1 for LTC6820
#define LINE_LTC_CS             PAL_LINE(GPIOA, 4)      // SPI1_NSS
#define LINE_LTC_SCLK           PAL_LINE(GPIOA, 5)      // SPI1_SCK
#define LINE_LTC_MISO           PAL_LINE(GPIOA, 6)      // SPI1_MISO
#define LINE_LTC_MOSI           PAL_LINE(GPIOA, 7)      // SPI1_MOSI

#define HW_SPI_DEV              SPID1
#define HW_SPI_AF               5

// LTC6811 (not LTC6813)
#define HW_LTC_TYPE             6811

/*===========================================================================*/
/* I2C for INA226                                                            */
/*===========================================================================*/

#define LINE_I2C_SDA            PAL_LINE(GPIOB, 7)      // I2C1_SDA
#define LINE_I2C_SCL            PAL_LINE(GPIOB, 6)      // I2C1_SCL

#define HW_I2C_DEV              I2CD1
#define HW_I2C_AF               4

/*===========================================================================*/
/* CAN Bus (via ISO1050 isolated transceiver)                                */
/*===========================================================================*/

#define LINE_CAN_RX             PAL_LINE(GPIOB, 8)      // CAN1_RX
#define LINE_CAN_TX             PAL_LINE(GPIOB, 9)      // CAN1_TX

#define HW_CAN_DEV              CAND1
#define HW_CAN_AF               9

/*===========================================================================*/
/* USB (via CP2104 USB-UART bridge)                                          */
/*===========================================================================*/

// CP2104 connects to USART - not native USB
#define LINE_USB_TX             PAL_LINE(GPIOA, 9)      // USART1_TX
#define LINE_USB_RX             PAL_LINE(GPIOA, 10)     // USART1_RX

#define HW_UART_DEV             UARTD1
#define HW_UART_AF              7
#define HW_UART_BAUDRATE        115200

/*===========================================================================*/
/* OLED Display (optional, I2C)                                              */
/*===========================================================================*/

#define HW_HAS_OLED
#define LINE_OLED_SDA           PAL_LINE(GPIOB, 11)     // I2C2_SDA
#define LINE_OLED_SCL           PAL_LINE(GPIOB, 10)     // I2C2_SCL
#define LINE_OLED_RST           PAL_LINE(GPIOC, 13)     // OLED reset

/*===========================================================================*/
/* Charge/Discharge Control                                                  */
/*===========================================================================*/

// High-side switch controls (active high via IRFL4105PBF)
#define LINE_CHG_EN             PAL_LINE(GPIOC, 6)      // Charge enable
#define LINE_DSG_EN             PAL_LINE(GPIOC, 7)      // Discharge enable
#define LINE_PCHG_EN            PAL_LINE(GPIOC, 8)      // Precharge enable

#define CHARGE_ENABLE()         palSetLine(LINE_CHG_EN); palSetLine(LINE_DSG_EN)
#define CHARGE_DISABLE()        palClearLine(LINE_CHG_EN); palClearLine(LINE_DSG_EN)
#define PRECHARGE_ENABLE()      palSetLine(LINE_PCHG_EN)
#define PRECHARGE_DISABLE()     palClearLine(LINE_PCHG_EN)

/*===========================================================================*/
/* Status LEDs                                                               */
/*===========================================================================*/

#define LINE_LED_RED            PAL_LINE(GPIOA, 0)      // Status LED (red)
#define LINE_LED_GREEN          PAL_LINE(GPIOA, 1)      // Power LED (green)

#define LED_RED_ON()            palSetLine(LINE_LED_RED)
#define LED_RED_OFF()           palClearLine(LINE_LED_RED)
#define LED_GREEN_ON()          palSetLine(LINE_LED_GREEN)
#define LED_GREEN_OFF()         palClearLine(LINE_LED_GREEN)

/*===========================================================================*/
/* Buzzer                                                                    */
/*===========================================================================*/

#define HW_HAS_BUZZER
#define LINE_BUZZER             PAL_LINE(GPIOA, 8)      // Buzzer output

/*===========================================================================*/
/* Inputs                                                                    */
/*===========================================================================*/

#define LINE_PWR_BTN            PAL_LINE(GPIOC, 9)      // Power button
#define LINE_CHG_DETECT         PAL_LINE(GPIOC, 10)     // Charger detect
#define LINE_SAFETY             PAL_LINE(GPIOC, 11)     // Safety interlock

/*===========================================================================*/
/* Temperature Sensing (NTC via LTC6811 GPIO)                                */
/*===========================================================================*/

// Thermistors connected to LTC6811 GPIO pins
#define HW_TEMP_SENSORS         3
#define LTC_GPIO_TEMP_0         1   // GPIO1 - Thermistor 1
#define LTC_GPIO_TEMP_1         2   // GPIO2 - Thermistor 2
#define LTC_GPIO_TEMP_2         3   // GPIO3 - Thermistor 3

// NTC parameters (100k @ 25°C, B=4250)
#define NTC_RES_25C             100000.0
#define NTC_BETA                4250.0
#define NTC_PULLUP              10000.0
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

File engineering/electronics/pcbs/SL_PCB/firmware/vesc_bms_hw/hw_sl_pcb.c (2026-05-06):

/*
    Copyright 2024 Benjamin Vedder  benjamin@vedder.se
    Copyright 2024 SL_PCB Contributors

    This file is part of the VESC BMS firmware.

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
    You should have received a copy of the GNU General Public License
    along with this program.  If not, see <http://www.gnu.org/licenses/>.
*/

#include "hw_sl_pcb.h"
#include "hal.h"
#include "ina226.h"

/*===========================================================================*/
/* Hardware Initialization                                                   */
/*===========================================================================*/

void hw_sl_pcb_init(void) {
    /*
     * GPIO Configuration
     */

    // LEDs (output, push-pull)
    palSetLineMode(LINE_LED_RED, PAL_MODE_OUTPUT_PUSHPULL);
    palSetLineMode(LINE_LED_GREEN, PAL_MODE_OUTPUT_PUSHPULL);
    LED_RED_OFF();
    LED_GREEN_OFF();

    // Buzzer (output, push-pull)
    palSetLineMode(LINE_BUZZER, PAL_MODE_OUTPUT_PUSHPULL);
    palClearLine(LINE_BUZZER);

    // Charge/Discharge control (output, push-pull, start disabled)
    palSetLineMode(LINE_CHG_EN, PAL_MODE_OUTPUT_PUSHPULL);
    palSetLineMode(LINE_DSG_EN, PAL_MODE_OUTPUT_PUSHPULL);
    palSetLineMode(LINE_PCHG_EN, PAL_MODE_OUTPUT_PUSHPULL);
    palClearLine(LINE_CHG_EN);
    palClearLine(LINE_DSG_EN);
    palClearLine(LINE_PCHG_EN);

    // Inputs (input with pull-up)
    palSetLineMode(LINE_PWR_BTN, PAL_MODE_INPUT_PULLUP);
    palSetLineMode(LINE_CHG_DETECT, PAL_MODE_INPUT_PULLUP);
    palSetLineMode(LINE_SAFETY, PAL_MODE_INPUT_PULLUP);

    // OLED reset (output, active low, start in reset)
    palSetLineMode(LINE_OLED_RST, PAL_MODE_OUTPUT_PUSHPULL);
    palClearLine(LINE_OLED_RST);

    /*
     * SPI1 for LTC6820 isoSPI
     */
    palSetLineMode(LINE_LTC_CS, PAL_MODE_OUTPUT_PUSHPULL);
    palSetLine(LINE_LTC_CS);  // CS high (inactive)

    palSetLineMode(LINE_LTC_SCLK, PAL_MODE_ALTERNATE(HW_SPI_AF));
    palSetLineMode(LINE_LTC_MISO, PAL_MODE_ALTERNATE(HW_SPI_AF));
    palSetLineMode(LINE_LTC_MOSI, PAL_MODE_ALTERNATE(HW_SPI_AF));

    /*
     * I2C1 for INA226
     */
    palSetLineMode(LINE_I2C_SDA, PAL_MODE_ALTERNATE(HW_I2C_AF) | PAL_STM32_OTYPE_OPENDRAIN);
    palSetLineMode(LINE_I2C_SCL, PAL_MODE_ALTERNATE(HW_I2C_AF) | PAL_STM32_OTYPE_OPENDRAIN);

    /*
     * CAN1
     */
    palSetLineMode(LINE_CAN_RX, PAL_MODE_ALTERNATE(HW_CAN_AF));
    palSetLineMode(LINE_CAN_TX, PAL_MODE_ALTERNATE(HW_CAN_AF));

    /*
     * USART1 for USB (via CP2104)
     */
    palSetLineMode(LINE_USB_TX, PAL_MODE_ALTERNATE(HW_UART_AF));
    palSetLineMode(LINE_USB_RX, PAL_MODE_ALTERNATE(HW_UART_AF));

    /*
     * I2C2 for OLED (optional)
     */
    palSetLineMode(LINE_OLED_SDA, PAL_MODE_ALTERNATE(HW_I2C_AF) | PAL_STM32_OTYPE_OPENDRAIN);
    palSetLineMode(LINE_OLED_SCL, PAL_MODE_ALTERNATE(HW_I2C_AF) | PAL_STM32_OTYPE_OPENDRAIN);

    // Release OLED from reset after a short delay
    chThdSleepMilliseconds(10);
    palSetLine(LINE_OLED_RST);

    /*
     * Initialize INA226 current sensor
     */
    ina226_init(HW_INA226_I2C_ADDR, HW_INA226_CAL);

    // Signal successful init
    LED_GREEN_ON();
}

/*===========================================================================*/
/* INA226 Current Reading                                                    */
/*===========================================================================*/

#ifdef HW_HAS_INA226

float hw_read_current(void) {
    int16_t raw = ina226_read_current_raw();
    // With calibration set for 1mA/LSB
    return (float)raw * 0.001f;  // Return in Amps
}

float hw_read_shunt_voltage(void) {
    int16_t raw = ina226_read_shunt_raw();
    // INA226 LSB = 2.5µV
    return (float)raw * 2.5e-6f;  // Return in Volts
}

#endif

/*===========================================================================*/
/* Temperature Reading                                                       */
/*===========================================================================*/

float hw_temp_cell_max(void) {
    // Returns maximum temperature from LTC6811 GPIO readings
    // This will be called by the VESC BMS main loop
    // Temperature conversion is done in ltc.c using NTC_TEMP macro
    extern float ltc_get_temp(int sensor);

    float max_temp = -273.15f;
    for (int i = 0; i < HW_TEMP_SENSORS; i++) {
        float temp = ltc_get_temp(i);
        if (temp > max_temp) {
            max_temp = temp;
        }
    }
    return max_temp;
}

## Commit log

2026-04-09 docs: remove field serviceability and connector details
2026-04-09 docs: add project words for spellcheck (Tattu, VESC)
2026-04-30 docs: add engineering layout
    [BMSJ.kicad_pcb, BMSJ.kicad_sch, BMSZ.kicad_pcb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]
2026-05-01 electronics: import Vector BMS as BMSJ
    [BMSJ.kicad_pcb, BMSJ.kicad_sch, MCU.kicad_sch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]
2026-05-01 Kicad Update
    Kicad
    [BMSJ.kicad_pcb]
2026-05-01 ci: exclude KiCad generated files from checks
2026-05-05 Copy BMSJ PCB files to BMSZ
    [BMSZ.kicad_pcb, BMSZ.kicad_sch, MCU.kicad_sch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]
2026-05-06 Kicad_Update
    - Add busbar cell connection
    - Screw holes
    - Edge cuts
    [BMSJ.kicad_pcb, BMSJ.kicad_sch, MCU.kicad_sch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]
2026-05-06 Ignore KiCad generated artifacts in checks
2026-05-06 Add SL_PCB layout copy
    [MCU.kicad_sch, SL_PCB.kicad_pcb, SL_PCB.kicad_sch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]
2026-05-06 Only leave basic layout in KiCad file
    [MCU.kicad_sch, SL_PCB.kicad_pcb, SL_PCB.kicad_sch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]
2026-05-06 Replace BMSZ with SL_PCB basic layout
    [BMSZ.kicad_pcb, BMSZ.kicad_sch, MCU.kicad_sch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]
2026-05-27 docs: add Longshot battery issue reference images
2026-05-27 docs: add voltage sensing board issue images
2026-05-27 docs: add SL_PCB TA3200 charge connector requirement
2026-05-27 docs: fix SL_PCB charger connector wording
2026-06-11 docs: add Longshot PT1 copper order artifacts
    [10X_0.2mm_copper_PW-BUS-001-N_Terminal.dxf, 10X_0.2mm_copper_PW-BUS-002-P_Terminal.dxf, 40X_0.2mm_copper_PW-BUS-003-Bridge_1.dxf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]
2026-06-11 docs: add PT1 cell BOM costs
2026-09-29 feat: extract longshot fusion placements and cots reference geometry
    Add tools/extract_reference.py, which reads Julius's Fusion export
    Longshot_Main_Assembly.step and writes the assembly tree, item and leaf
    placements and per-part reference metrics to src/longshot/placements.json,
    plus gzip-compressed reference STEPs for purchased and PCB parts.
2026-09-29 feat: add longshot cots wrappers and main assembly rebuild
    Purchased and PCB parts load their extracted reference STEP through
    longshot.cots. longshot.assembly rebuilds the Fusion tree from
    placements.json as a labelled build123d compound, checks its bbox against
    the Fusion export and writes per-part STEP/STL plus the assembly STEP.
2026-09-30 feat: add parametric build123d parts for longshot custom components
    One module per custom part number (cell, busbars, cell holders, plates,
    reinforcement sheets, printed base and top cover, strap), with key
    dimensions probed from Julius's Fusion solids. tools/validate_parts.py
    compares each part with its reference (bbox, volume, symmetric
    difference) and writes validation/results.md. All parts pass except the
    printed top cover, which sits at the 2 % sym-diff limit.
2026-09-30 feat: add longshot per-part step and stl exports
    Generated with python -m longshot.assembly. The full assembly STEP
    (about 75 MB, mostly vendor models) stays git-ignored and is regenerated
    locally. Generated CAD exports are excluded from editorconfig checks.
2026-09-30 docs: add longshot build123d bom, readme and preview
    tools/generate_bom.py counts one pack from the Fusion tree and writes
    BOM.md and BOM.csv with category, make/buy, material, source links and
    validation status. Purchase records stay in the PT1 BOM, which is linked.
    The README documents the source export, setup and the extract, validate,
    build and BOM commands.
2026-09-30 docs: record Julius's answers on bridge flat pattern, main fuse and cell model
2026-09-30 fix: gzip longshot stl exports and add cad words so spell check passes
2026-10-19 ci: exclude kicad production and vendor model files from editorconfig, add sl_pcb words
2026-10-19 feat: update sl_pcb kicad project from julius's latest project folder
2026-10-19 fix: correct typos in sl_pcb terminal descriptions, title note and footprint value

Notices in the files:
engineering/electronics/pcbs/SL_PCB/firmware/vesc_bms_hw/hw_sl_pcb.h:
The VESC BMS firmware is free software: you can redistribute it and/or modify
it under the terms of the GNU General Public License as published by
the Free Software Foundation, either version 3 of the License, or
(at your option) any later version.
